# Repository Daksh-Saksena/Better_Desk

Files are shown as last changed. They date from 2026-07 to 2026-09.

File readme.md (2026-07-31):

# BetterDesk

A workbench that can **see**, **understand** and **physically interact** with everything on your desk.

---

## What is BetterDesk?

BetterDesk is an interactive workbench designed to make building electronics, robotics, hardware projects, art, etc much easier and more importantly COOLER!

Instead of just sitting there like a normal desk, BetterDesk knows whats on your workspace using multiple cameras and computer vision. It can identify components, answer questions, guide you through builds, organize your parts and even **move objects around the desk itself** using a custom built programmable motion surface.

Its like a mix between an electronics workbench, an AI assistant like clawdbot, a giant programmable trackpad, and a pick and place machine but with conveyer built technology for real world objects.

I KNOW IT SOUNDS CONFUSING BUT TRUST ME you'll understand.

---

## Why?

We all have spend a lot of time building electronics projects and somehow always the desk, laptop and brain always jumble up into 1 confusing mess of switching between videos, pin outputs, code and the physical parts randomly getting lost in the jumble of jumper wires u refuse to untangle.

Current AIs can answer questions but they ofc can't actually interact with your physical workspace.

SO after not watching the iron man movie but instead watching a yt short summary about it. I realised...

**What if the desk could become jarvis?** 
not that the desk would start flying or whatever jarvis does. But what if it could see what you're building , help you by showing instructions ON the desk itself and move components for you. 

Instead of opening another browser tab, the desk should know what you're building, point at the correct components, organize everything automatically and even move parts around for you.

---

# 4 main parts:

### 1. The software:

Ok so this is the part that makes the entire project smart. We use 2 cameras -> 1 ipad camera and 1 iphone camera (in reality you would use smaller independant cameras but we dont have budget lol) which can basically see the entire desk area. The 2 cameras are then calibrated together to create a single 3D grid using simple triangulation from calibration. This helps improve depth perception while keeping the images clear.

After getting these pics, we trained a big YOLOv11 model on approximately 4000 pictures of manually annotated electric component pics, by doing this the we find the position of the electric components on the desk as it gives cords relative to the camera visible area. So as we place 4 Araku markers around the corners with some simple subtraction it knows the exact position. All of this with the image is sent to a GPT4o api call. It identifies whats generally happening and then we pair this with our voice assistant which is just a simple open AI whispr transcriber which sends the text to the same APi call and then the response is said outloud by elevenLabs.

BUT the main thing is since we have the position of the components we can draw bounding boxes around them and then draw boxes arrows and text to where the component should be placed/ already is placed and other instructions. Also i plan to implement a feature such that the AI can look up guides and show part of the website but before that i want the projector working first as it would be much easier to know where/when/how to place the instructions. SO all of this is planned to run on the main raspberry pi 5

---

### 2. The Projector:

---

### 3. The Desk:

---

### 4. The Control Panel:

Ok so for some basic controls like controlling volume and switching between modes. We are going to build a small control panel which will connect directly to the raspberry pi. Its made up of a touch sensor layer + the LCD screen from my ender3 + arduino uno.

---

# Gallery

---

## Full CAD Assembly of Desk

---

## Full CAD Assembley of Projector

---

## FULL Wiring Diagram

---

## Current Software

---

# Future Plans

Ofc build the full thing in build review but also make software more capable than simply drawing boxes and arrows. But as i mentioned id prefer to do that after the projector is built so i can get a feel of how the instructions will look best

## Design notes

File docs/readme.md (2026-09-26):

REVIEWER NOTE: PLEASE read the final journal as it contains a lot of clarification

# BetterDesk

A workbench that can **see**, **understand** and **physically interact** with everything on your desk.
---

## What is BetterDesk?

BetterDesk is an interactive workbench designed to make building electronics, robotics, hardware projects, art, etc much easier and more importantly COOLER!

Instead of just sitting there like a normal desk, BetterDesk knows whats on your workspace using multiple cameras and computer vision. It can identify components, answer questions, guide you through builds, organize your parts and even **move objects around the desk itself** using a custom built programmable motion surface.

Its like a mix between an electronics workbench, an AI assistant like clawdbot, a giant programmable trackpad, and a pick and place machine but with conveyer built technology for real world objects.

I KNOW IT SOUNDS CONFUSING BUT TRUST ME you'll understand.

---

## Why?

We all have spend a lot of time building electronics projects and somehow always the desk, laptop and brain always jumble up into 1 confusing mess of switching between videos, pin outputs, code and the physical parts randomly getting lost in the jumble of jumper wires u refuse to untangle.

Current AIs can answer questions but they ofc can't actually interact with your physical workspace.

SO after not watching the iron man movie but instead watching a yt short summary about it. I realised...

**What if the desk could become jarvis?** 
not that the desk would start flying or whatever jarvis does. But what if it could see what you're building , help you by showing instructions ON the desk itself and move components for you. 

Instead of opening another browser tab, the desk should know what you're building, point at the correct components, organize everything automatically and even move parts around for you.

---

# 4 main parts:

### 1. The software:

Ok so this is the part that makes the entire project smart. We use 2 cameras -> 1 ipad camera and 1 iphone camera (in reality you would use smaller independant cameras but we dont have budget lol) which can basically see the entire desk area. The 2 cameras are then calibrated together to create a single 3D grid using simple triangulation from calibration. This helps improve depth perception while keeping the images clear.

After getting these pics, we trained a big YOLOv11 model on approximately 4000 pictures of manually annotated electric component pics, by doing this the we find the position of the electric components on the desk as it gives cords relative to the camera visible area. So as we place 4 Araku markers around the corners with some simple subtraction it knows the exact position. All of this with the image is sent to a GPT4o api call. It identifies whats generally happening and then we pair this with our voice assistant which is just a simple open AI whispr transcriber which sends the text to the same APi call and then the response is said outloud by elevenLabs.

BUT the main thing is since we have the position of the components we can draw bounding boxes around them and then draw boxes arrows and text to where the component should be placed/ already is placed and other instructions. Also i plan to implement a feature such that the AI can look up guides and show part of the website but before that i want the projector working first as it would be much easier to know where/when/how to place the instructions. SO all of this is planned to run on the main raspberry pi 5

---

### 2. The Projector:

The projector is probably one of the weirdest parts of the project. Instead of buying a normal projector (way too expensive ), we're building one completely from scratch. It uses a 50W COB LED as the light source, which is bright enough to project onto roughly a 50cm × 50cm workspace even in a reasonably lit room. Since a 50W LED gets ridiculously hot, it's mounted to an aluminium heatsink with a CPU cooler so nothing melts. The image itself comes from the LCD panel salvaged from an old broken tablet. We literally took the tablet apart, removed the LCD (and removed it from its backlight) and use it as the projector's imaging panel. A Raspberry Pi Zero drives the LCD through a TTL display controller board.

Light from the LED passes through a condenser lens, then through the tablet LCD, before being focused by a collector lens and finally projected using a larger projection lens. Because the projector can't be mounted directly above the desk, the entire optical assembly is mounted on an adjustable mechanism with a ratchet-and-pawl locking system. A stepper motor adjusts distances between the projector and collector lens. Every mount for the lenses, LCD, LED, cooling system and adjustment mechanism is being custom designed in CAD so everything stays aligned while still being as compact (and cheap) as possible. Theres also a linear actuator which changes the angle of the projector lens to be able to focus the image using some random physics principle. It definitely isn't the easiest way to build a projector but it's a lot more fun. 

---

### 3. The Desk:

The desk movement system is one of the most complex parts of this project. It uses a grid of x and y rods moving with a suspended ball between them. A piston below the ball controls whether it touches the x rod on top or the y rod below. Each piston system is controlled in a sort of coordinate grid, in a grid formed by 10 x and 10 y pressure pipes running below the whole rod system. Suppose at a point, the system gets a positive pressure from the x pressure pipe and a positive pressure from the y pressure pipe. Then the ball moves up. If both pipes have negative pressure, the ball moves down. If both are opposite [like on positive and one negative], the ball stays stationary. The pressure in the pressure pipes are controlled by pumps, which are controlled by an ESP32. The ESP32 also controls the NEMA17 motors, which move the rods. There are a total 100 ball units, forming a grid of 10x10

---

### 4. The Control Panel:

Ok so for some basic controls like controlling volume and switching between modes. We are going to build a small control panel which will connect directly to the raspberry pi. Its made up of a touch sensor layer + the LCD screen from my ender3 + arduino uno.

---

# Gallery

---

## Full CAD Assembly of Desk
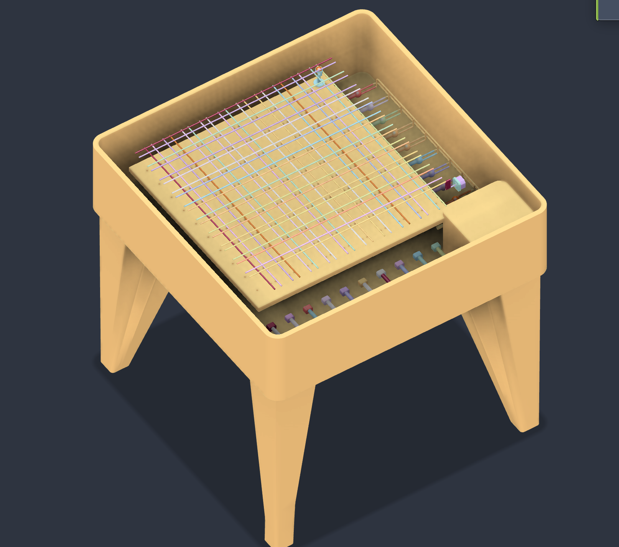
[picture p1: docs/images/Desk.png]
Desk

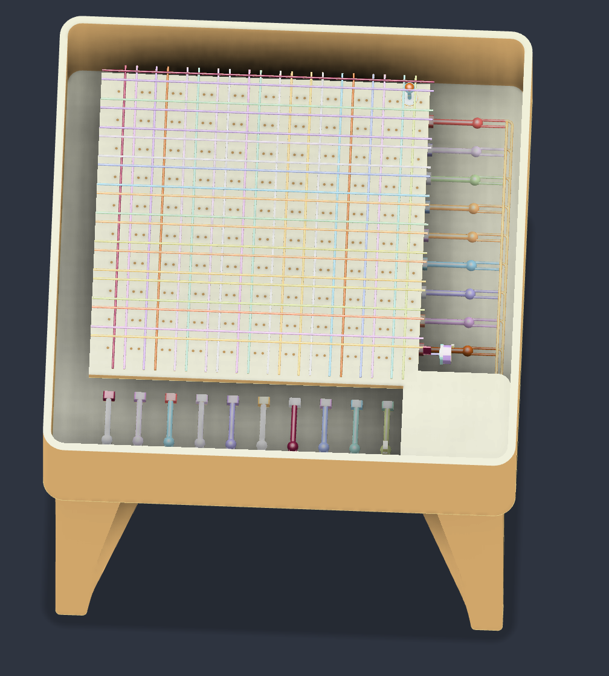
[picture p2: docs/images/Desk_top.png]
Desk_Top


---

## Full CAD Assembley of Projector



---

## FULL Wiring Diagram

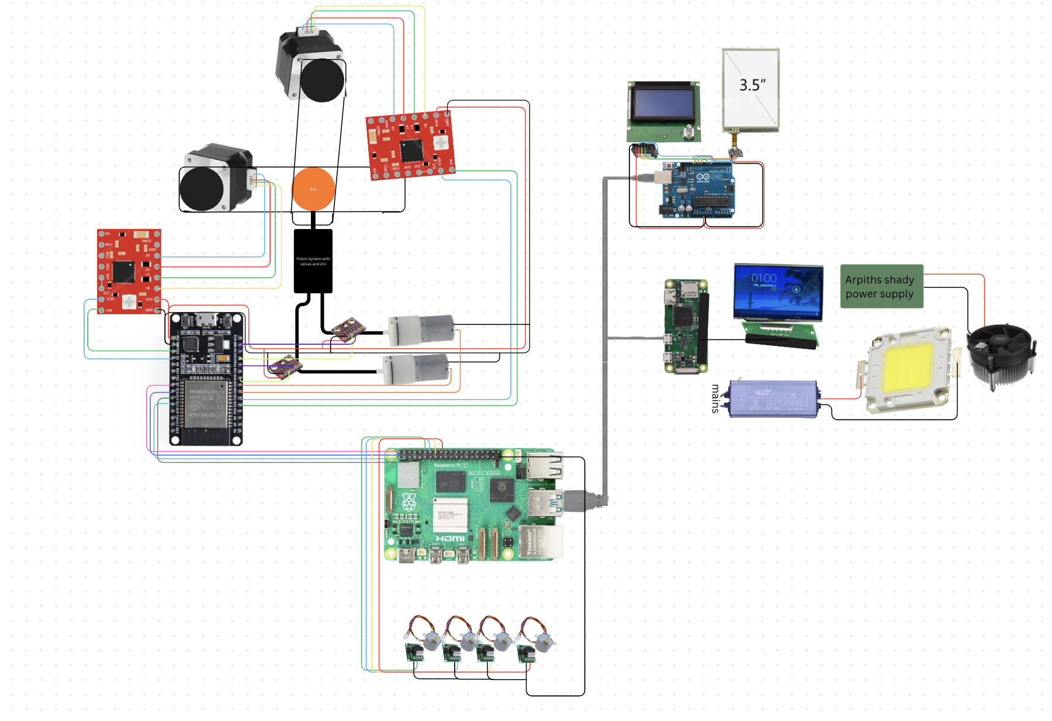
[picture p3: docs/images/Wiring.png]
Wiring


---

## Current Software
<p align="center">
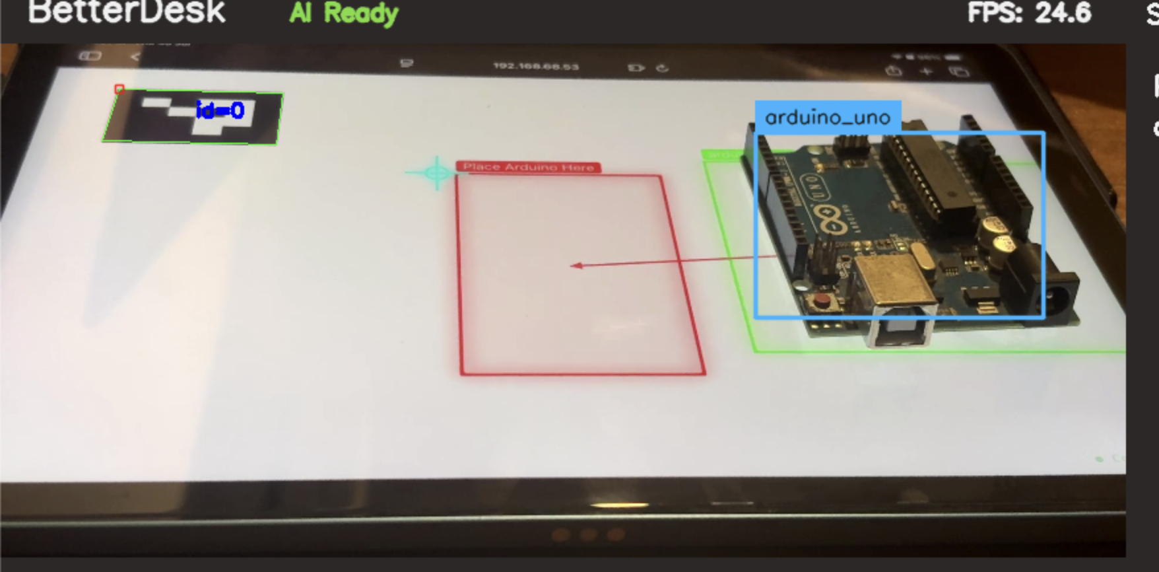
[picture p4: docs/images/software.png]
  
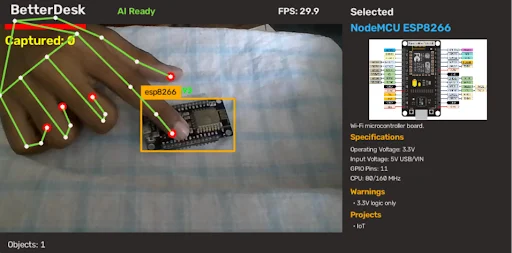
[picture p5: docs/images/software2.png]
  
</p>

---

# Bill Of Materials
|Item |Specific part |Unit Price (inr)|Quantity|Total Price ₹|Total Price $|URL |Running Total ₹|Running Total $|
|---|---|---|---|---|---|---|---|---|
|Balls |Polypropylene Balls |₹5.00 |110 |₹550.00 |$5.74 |https://dir.indiamart.com/impcat/polypropylene-balls.html |₹550.00 |$5.74 |
|Rollers |50cm Aluminium rollers |₹306.00 |10 |₹3,060.00 |$31.94 |https://www.amazon.in/Zaymircozy-Smooth-Printer-Robotics-Projects/dp/B0FH2KFWB4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 |₹3,610.00 |$37.68 |
|Mosfets, Schottky diodes, Resistors|Alr have |₹0.00 |10 |₹0.00 |$0.00 | |₹3,610.00 |$37.68 |
|Motors |NEMA 13 STEPPER (already have from ender) |₹0.00 |1 |₹0.00 |$0.00 | |₹3,610.00 |$37.68 |
|Motor driver |A4988 motor driver with heat sink |₹699.00 |1 |₹699.00 |$7.30 |https://www.amazon.in/TESTIN-ELECTRONICS-Stepper-Heatsink-Printer/dp/B0GGTFJJT7 |₹4,309.00 |$44.97 |
|Piping |Polyurethane Pneumatic Air Tube |₹175.00 |3 |₹525.00 |$5.48 |https://www.amazon.in/Polyurethane-Pneumatic-Flexible-Compressor-Industrial/dp/B0HFCSDDWX/ref=sr_1_1 |₹4,834.00 |$50.45 |
|Pumps |6V to 12V Mini |₹89.00 |23 |₹2,047.00 |$21.36 |https://quartzcomponents.com/products/12v-dc-1-2l-min-mini-vacuum-pump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 |₹6,881.00 |$71.81 |
|Pressure Sensor |BMP280 |₹34.00 |25 |₹850.00 |$8.87 |https://www.flyrobo.in/bmp280-barometric-pressure-and-altitude-sensor-i2c-spi-module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 |₹7,731.00 |$80.68 |
|LED |50W 32V Natural White SMD COB LED |₹699.00 |1 |₹699.00 |$7.30 |https://probots.co.in/50w-32v-natural-white-smd-cob-led-rectangle-light.html |₹8,430.00 |$87.98 |
|Cooler |Cooler Master i30 CPU Cooler |₹655.00 |1 |₹655.00 |$6.84 |https://www.amazon.in/Cooler-Master-i30-CPU-Aluminum/dp/B09V4PN9MX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 |₹9,085.00 |$94.82 |
|Condensor Lens |High Power LED 20-100W Lens |₹300.00 |1 |₹300.00 |$3.13 |https://roboman.in/product/high-power-led-20-100w-lamp-bead-lens-44mm-optical-glass-lens-50-mm-reflective-collimator-fixed-bracket-60-120-degree-led-lens/ |₹9,385.00 |$97.95 |
|Collector Lens |Convex Lens F20 D100 |₹300.00 |1 |₹300.00 |$3.13 |https://www.amazon.in/ERH-India-Magnifier-Convex-Length/dp/B09BNTC9F5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 |₹9,685.00 |$101.08 |
|Projector Lens |Convex Lens F10 D75 |₹270.00 |1 |₹270.00 |$2.82 |https://www.amazon.in/Diameter-75-Science-Experiments-Projects-Microscopes/dp/B0C576XYVT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,aps,273&xpid=PNhMk0UkOY3Z4 |₹9,955.00 |$103.90 |
|LCD display without backlight |Extracted from eshants tablet |₹0.00 |1 |₹0.00 |$0.00 | |₹9,955.00 |$103.90 |
|LED driver |50W LED driver |₹150.00 |1 |₹150.00 |$1.57 |https://makerbazar.in/products/50w-led-driver-1500ma-300ma-750ma |₹10,105.00 |$105.46 |
|60 pin RGB TTL breakout board |FPC FFC 60 Pin Adapter |₹101.00 |1 |₹101.00 |$1.05 |https://roboticsdna.in/product/fpc-60pin-cable-pitch-0-5mm-to-dip-pitch-2-54mm-smt-adapter-pcb-board/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 |₹10,206.00 |$106.52 |
|Controller of LCD screen |Raspberry Pi 0 |₹1,299.00 |1 |₹1,299.00 |$13.56 |https://robu.in/product/raspberry-pi-zero-v1-3-development-board/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 |₹11,505.00 |$120.07 |
|Stepper Motors |8BYJ-48 Stepper Motor + ULN2003 Driver |₹139.00 |4 |₹556.00 |$5.80 |https://probots.co.in/28byj-48-stepper-motor-and-uln2003-stepper-motor-driver.html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 |₹12,061.00 |$125.87 |
|Ball Valve Motors |MG996R |₹259.00 |20 |₹5,180.00 |$54.06 |https://quartzcomponents.com/products/mg996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 |₹17,241.00 |$179.94 |
|Ball Valve Controller |Raspberry pi Pico |₹384.00 |1 |₹384.00 |$4.01 |https://robu.in/product/raspberry-pi-pico/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 |₹17,625.00 |$183.94 |
|Control Board for motors |ESP32 |₹589.00 |2 |₹1,178.00 |$12.29 |https://www.amazon.in/SquadPixel-ESP-32-Bluetooth-Development-Board/dp/B071XP56LM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|₹18,803.00 |$196.24 |
|Main Control Board |Raspberry pi 5 |₹0.00 |1 |₹0.00 |$0.00 | |₹18,803.00 |$196.24 |
|Springs |Stainless Steel Mini Compression Springs |₹1.00 |110 |₹110.00 |$1.15 |https://www.indiamart.com/proddetail/mini-compression-springs-21559716612.html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 |₹18,913.00 |$197.39 |
|Camera |Phone camera + ipad camera (already have) |₹0.00 |1 |₹0.00 |$0.00 | |₹18,913.00 |$197.39 |
|Resin |Fast Curing UV Epoxy Resin |₹399.00 |4 |₹1,596.00 |$16.66 |https://www.amazon.in/Resin-Hard-Type-Crystal-Clear/dp/B0GYFDFBJT?th=1 |₹20,509.00 |$214.04 |
|UV light |Ultra Violet LED UV Light 390-395nm Purple  |₹289.00 |2 |₹578.00 |$6.03 |https://www.amazon.in/Invento-Violet-390-395nm-Purple-Projects/dp/B07GD1G6H3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 |₹21,087.00 |$220.07 |
|3D Printing |lots of parts (mostly self funded) |₹0.00 |1 |₹0.00 |$0.00 | |₹21,087.00 |$220.07 |
|Control Panel Board |Arduino Uno (alr have) |₹0.00 |1 |₹0.00 |$0.00 | |₹21,087.00 |$220.07 |
|Control Panel Display |Scrapped from Ender 3 LCD |₹0.00 |1 |₹0.00 |$0.00 | |₹21,087.00 |$220.07 |
|Control Panel Touchscreen |3.5 inch 4 Wire Resistive Touch Screen Panel|₹150.00 |1 |₹150.00 |$1.57 |https://kitsguru.com/products/3-5-inch-4-wire-resistive-touch-screen-panel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 |₹21,237.00 |$221.64 |
|Control Panel Touch controller |5767 TSC2046 SPI Resistive Touch |₹581.00 |1 |₹581.00 |$6.06 |https://www.fabtolab.com/adafruit-5767-tsc2046-spi-resistive-touch-screen-controller |₹21,818.00 |$227.70 |

---

# Future Plans

Ofc build the full thing in build review but also make software more capable than simply drawing boxes and arrows. But as i mentioned id prefer to do that after the projector is built so i can get a feel of how the instructions will look best

If You Want to run the code ,in the .env Please put an OpenAi key and a elevenlabs key and then run python src/core/detector.py

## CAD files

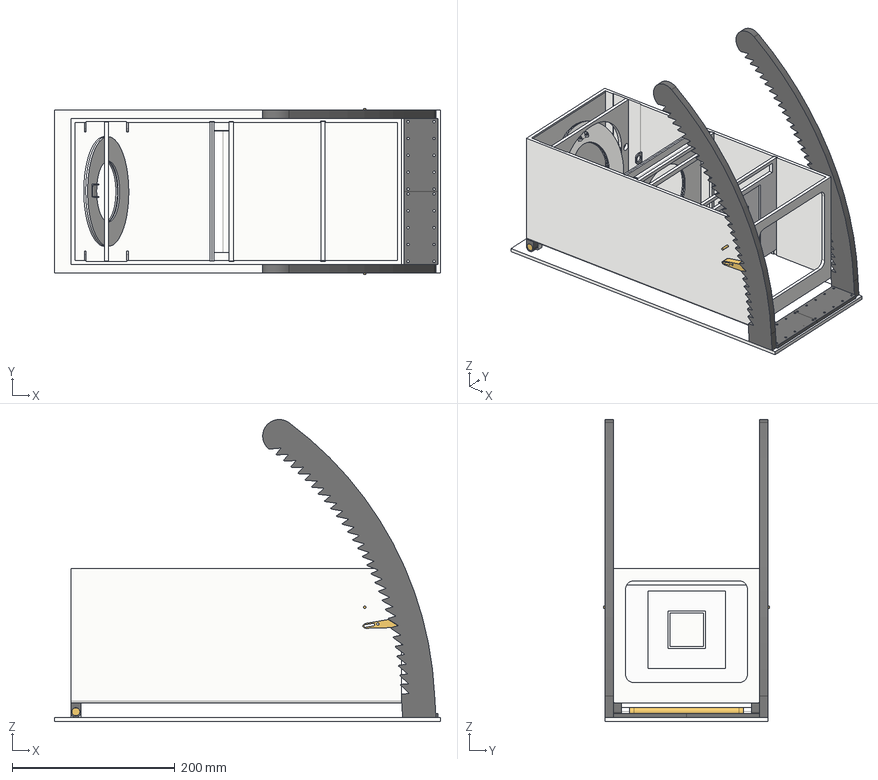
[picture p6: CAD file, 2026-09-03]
Projector/assembly.step
475.0 x 204.0 x 371.7 mm

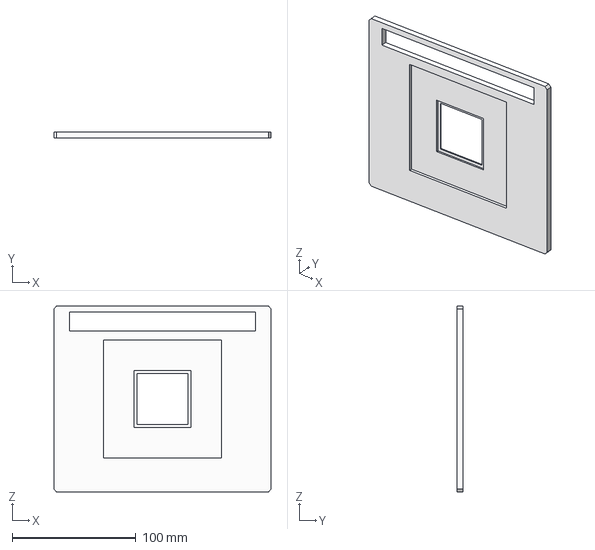
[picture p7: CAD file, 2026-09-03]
Projector/LED mount.step
175.0 x 5.00 x 150.0 mm

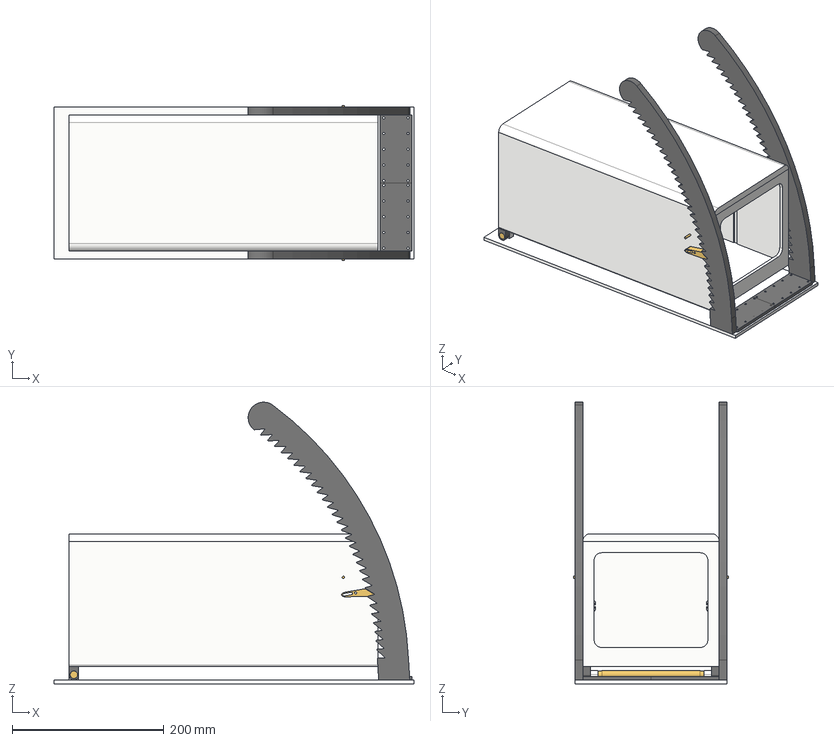
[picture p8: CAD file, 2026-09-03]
Projector/housing.step
475.0 x 204.0 x 371.7 mm

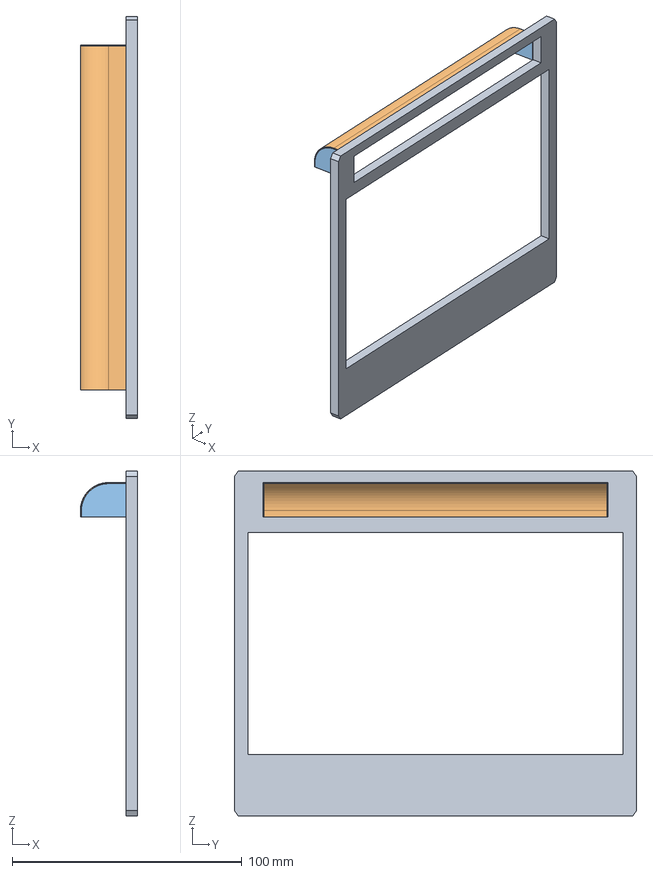
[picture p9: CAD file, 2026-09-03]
Projector/LCD mount.step
25.0 x 175.0 x 150.0 mm

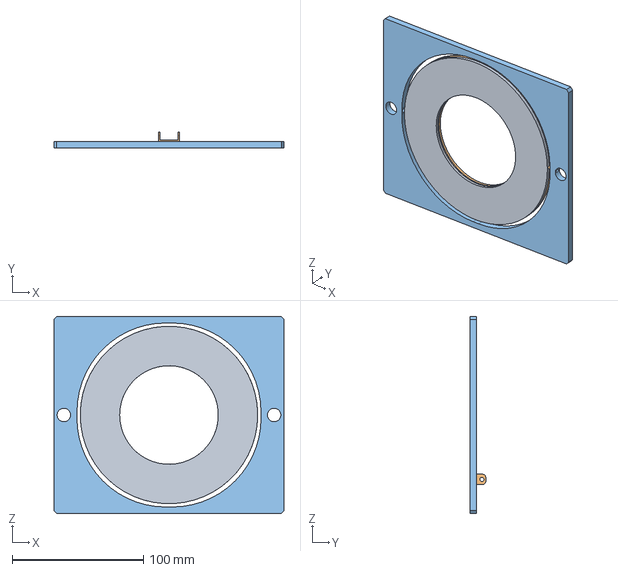
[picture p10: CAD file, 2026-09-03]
Projector/Projector Lens mount.step
175.0 x 12.0 x 150.0 mm

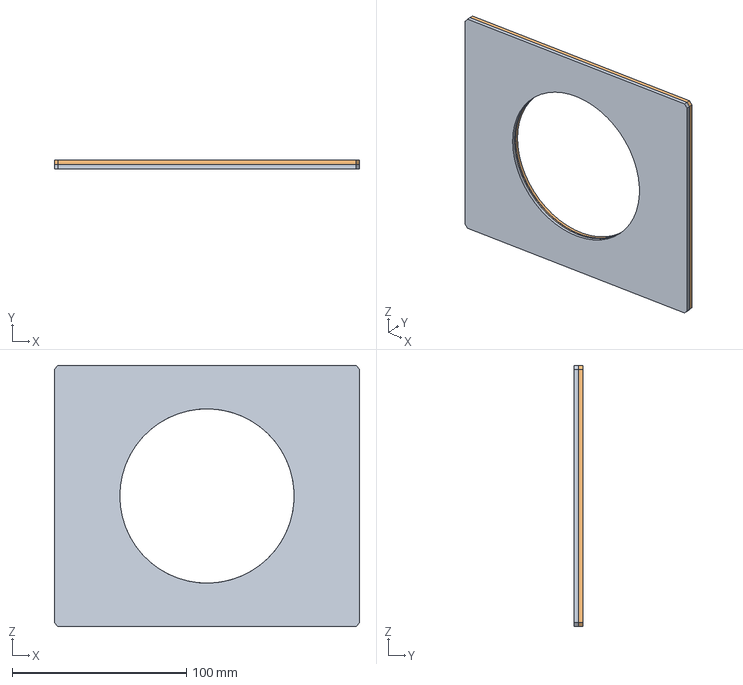
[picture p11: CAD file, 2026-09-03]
Projector/Condensor lens mount.step
175.0 x 5.00 x 150.0 mm

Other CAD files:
Projector/Condensor lens mount.f3d
Projector/LCD mount.f3d
Projector/LED mount.f3d
Projector/Projector Lens mount.f3d
Projector/assembly.f3z

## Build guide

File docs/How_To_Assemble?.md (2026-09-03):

# How to Assemble BetterDesk

## 1. What are we building?

BetterDesk has five main pieces:

1. Programmable motion surface, a 10x10 grid of balls that can move objects around.
2. Motor + rod system, motors spin threaded rods which transfer motion through the mechanical cells.
3. AI/vision system, two cams + software.
4. Projection system, a custom projector.
5. Control panel, an Arduino small touchscreen interface.

The Pi 5 is the main computer for the overall system. Separate microcontrollers handle some of the specific system things.

The important part is to get one mechanical cell working first. There is no point assembling 100 cells and then discovering that the ball is slipping or the rod geometry is wrong!

---

# 2. Mechanical surface

## 2.1 Prepare the grid

Build the main frame according to the CAD model and create the 10x10 ball positions.

Each grid point assembly should have:

- a ball
- spring
- all the 3Dp stuff
- tubing

Use the CAD dimensions as the source of truth for spacing.

Do the same for the springs: install one spring per active cell and keep the remaining springs as spares (cus you're gonna break a lot).

## 2.2 Install the rods

Fit the threaded rods through the mechanical system according to the CAD.

The nema motors will spin a basic gear system such that 1 motor can spin 5 threaded rods and the mechanism transfers that motion to the balls.

Before doing the whole surface, get ONE cell working first. Make sure the rod spins properly, the ball moves properly and the spring returns everything to its position.

## 2.3 Motors

Mount the motors to the frame and connect them to the threaded rods. both NEMA 13 stepper motors and 28BYJ-48 motors with ULN2003 drivers. Connect the motor drivers and ESP32 boards acc to the wiring diagram (ignore that its made in canva lol)

---

# 3. Pneumatic system / piping system

SO THIS IS divided into 2 main parts, the pnuematic thingabob and the piping madness.

For the piping madness since we are printing a 2 way into a 1 way thingy i frgt the name, it will basically connect to 1 X and 1 Y pipe.

SO now u do this for all 10 + 10 pipes -> 20 pipes and then u have a XnY grid! 

Install the pumps at end of each pipe and route the tubing through the relevant parts of the mechanism.

Connect the pressure sensors to the pneumatic sections and make sure the tubing connections are secure.

Test one complete cell before connecting everything together otherwise ull build everything and realise ur pipe is too thick by 0.00000001 micrometer and u gotta redo everything.

---

# 4. Main electronics

The Raspberry Pi 5 is the main computer for BetterDesk.

It handles the overall software, AI system, vision system and communication between the different parts.

The ESP32 boards handle the motor control side.

Connect the Raspberry Pi, ESP32s and motor drivers acc to the wiring diagram, PLEASE follow the wiring diagram, i sweated it for like 3 hours.

Keep the power connections separate for the different systems and use the wiring diagram as the reference.

---

# 5. AI and vision system

Mount any phone camera and tablet camera so they can see the whole workspace.

The cameras are Auto calibrated together so the software can understand the workspace in 3D.

Place four ArUco markers around the corners of the workspace. These give the software a reference for where objects are.    

OR

u be an idiot like me and u manually take 50 pics for calibration EVERY TIME using some random ass python library

The software uses:

- stereo camera calibration
- YOLOv11 <- the GOAT
- ArUco markers 
- GPT-4o <- stinky (grok better /j)
- Whisper 
- ElevenLabs

Once the software knows where objects are, those positions can also be used by the projector to show boxes, arrows, labels, instructions, guides, yt shorts ANYTHING

---

# 6. Projector

The projector is built around a 50W COB LED.

The optical setup is:

LED -> condenser lens -> LCD -> collector lens -> projector lens

The LCD is taken from an eshants stinky farty old broken tablet and used without its original backlight)

## 6.1 LED and cooling

Mount the LED onto the aluminium cooling assembly (get it from ur uncle or js bend the metal with ur bare hands) and attach the CPU cooler.

The 50W LED produces a SHI TON of heat, so make sure the cooling system is properly mounted before running it.

## 6.2 LCD and lenses

Install the tablet LCD into its mount.

Current lenses:

- 100 mm diameter, 200 mm focal length collector lens
- 75 mm diameter, 100 mm focal length projector lens
- 100mm diameter, 100mm focal length condensor lens

Use the CAD dihmensions for the exact spacing.

## 6.3 Projector mount

Mount the projector onto the adjustable mechanism.

The current design uses a ratchet and pawl mechanism to hold the projector angle. The optical assembly can then be adjusted to get the image aligned with the workspace.

---

# 7. Control panel

The control panel is another thing i scrapped and saved 0.00001$

It uses:

- Arduino Uno
- Ender 3 LCD (if u dont have this , uh get a normal LCD of simmilar size and adjust CAD accordingly)
- 3.5 inch 4 wire resistive touchscreen
- TSC2046 touch controller (needed for the above)

Mount the touchscreen over the display and connect the touch controller to the Arduino.

The Arduino handles the control panel and communicates with the Pi.

---

# 8. Airtight

Some parts need to be airtight, but printing all of them in SLA would be WAY WYA WYAYW YAYWYWYAYAYY too expensive.

Instead, print the part in PLA and coat it with UV resin.

Then slowly rotate the part while curing it under the UV lights. This should give an even coating while letting us control the curing time.

Test the process on a small part first before doing important parts.
^
|
OK SO THIS IDEA IS WHAT ESHANT TOLD ME, IF IT DOESNT WORK GG FOR US

---

# 9. Final assembly

Once the individual parts work:

1. Finish the mechanical grid.
2. Install the threaded rods and motors.
3. Install the pumps, tubing and pressure sensors.
4. Connect the ESP32 motor control.
5. Connect the Raspberry Pi 5.
6. Install the cameras and ArUco markers.
7. Assemble the projector.
8. Add the control panel.
9. Run the software and calibrate the workspace.

AGAIN TO REITERATE -> The first milestone should be one complete working cell. Once that works, scale it up to the full 10x10 surface!!

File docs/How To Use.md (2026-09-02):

How to Use

BetterDesk is designed to be used as an interactive computer-vision workbench. Once the software and required hardware are connected, position the cameras so that the working area of the desk
is visible and place the ArUco markers around the workspace. The cameras provide the visual input used by the detection system, while the markers define the physical workspace and allow
detected component positions to be mapped to locations on the desk.

Start the BetterDesk software from the project environment and allow the camera feeds to initialise. The computer-vision pipeline continuously analyses the camera frames and searches for 
supported electronic components using the trained YOLOv11 detection model. When a component is detected, BetterDesk places a bounding box around it and identifies the component. 
The detection information can then be used by the rest of the system to understand what is currently on the workspace and where it is located.
To inspect a component, point toward it within the camera's view. The interface can select the detected component and display an information panel containing its name, image, description,
specifications, warnings, and examples of projects it can be used in. The visual interface also displays the current system status and processing FPS, while the bottom status bar provides
feedback about what the system is currently doing. If the system is organising the workspace, the interface displays an “Organising Desk...” status.
BetterDesk can also be interacted with using voice. Speak a question or command through the connected microphone and the voice system transcribes the speech before passing the text
along with the detected workspace information to the AI system. This allows the user to ask about components or the current workspace without having to manually identify every part. 
Responses can then be returned through the voice interface. There is also another way, that is through gestures. The user can display simple hand gestures like the peace sign, the devil horns sign, etc, which perform tasks like re-organising the workspace, moving objects, etc. 
For physical workspace interaction, the detected component coordinates are converted into desk-space positions using the camera calibration and ArUco reference points. These coordinates are
intended to allow BetterDesk to determine where objects are located and provide instructions for where they should be placed. The programmable desk mechanism can then move its individual ball
units using the X/Y motion system. The physical system uses an ESP32 to control the motors and pressure system, allowing objects on the workspace to be moved across the desk.
The projection system is used to extend the computer-vision interface onto the physical workspace. Once the projector is connected and calibrated, visual information such as bounding boxes,
arrows, labels, and placement instructions can be projected directly onto the desk rather than requiring the user to constantly look at a separate screen. The projection subsystem contains
the ArUco calibration helper, overlay manager, renderer, and server components used to create and manage these projected overlays.

A typical BetterDesk session therefore follows this workflow:

Prepare the workspace
           
Start the software

Place components on the desk

Allow detection

Inspect components

Ask questions by voice

Follow visual guidance

Organise the workspace

Build and interact

The repository represents an actively developed prototype, so not every part of the complete physical system is necessarily required or operational at the same time. The software is divided into separate components for detection, UI rendering, voice interaction, projection, and model training. The physical desk, projector, and control-panel systems are developed as separate subsystems and can be integrated progressively as the hardware is completed.

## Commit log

2026-06-10 calibrated with better pinching featur
2026-07-05 les goooo
2026-07-26 Switch to offline Ultralytics MPS AI, add manual calibration (k), and restrict UI to index finger
2026-07-31 WIRING DIGRAM DONE!!
2026-07-31 BOM changes!
    [BOM.csv]
2026-08-02 fixing BOM
    [BOM.csv]
2026-08-02 another small change to BOM
    [BOM.csv]
2026-08-02 small changes part 2
    [BOM.csv]
2026-09-02 Add CAD files and STEP repository as submodule
2026-09-02 update BOM
    [BOM.csv]
2026-09-02 update bom in dreadme
2026-09-02 v1 how to assemble
2026-09-02 assembley instrcutionsasdajdpasjd
2026-09-03 daks stop crying
    [Condensor lens mount.f3d, Condensor lens mount.step, LCD mount.f3d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]
2026-09-04 Restore CAD submodule configuration
2026-09-04 Update CAD submodule to latest main
2026-09-04 Add automatic CAD submodule updates
2026-09-04 Fix CAD submodule path
2026-09-04 Configure CAD submodule to track main
2026-09-04 Automatically update CAD submodule
2026-09-04 Add direct CAD latest main links to documentation and enhance updater workflow
    - Add prominent links in docs/readme.md to the CAD repository main branch (https://github.com/eshantsonhar/Betterdesk---cad-model/tree/main)
    - Clarify distinction between pinned reproducible submodule gitlink and live latest CAD branch
    - Improve update-cad-submodule workflow with concurrency control, error handling, and clean UTF-8 encoding
2026-09-05 FINAL CAD UPDATE!
2026-10-22 Add tablev8.stl to Desk_CAD via Git LFS
2026-10-24 Add new items and update BOM.csv
2026-10-29 how to assemble assembled
2026-10-29 detailing assembley
